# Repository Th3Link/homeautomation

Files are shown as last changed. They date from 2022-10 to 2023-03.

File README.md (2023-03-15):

# homeautomation

In this repository you can find components for a CANBus home automation system.

## mqtt_gateway
The gateway is used to access the canbus via MQTT but it also has some very useful features
for the canbus maintainance. It features a web interface (currently unencrypted http)
which enables you to make some settings for the gateway, view modify and update all your attached
devices on the can bus and update the gateway itself. It translates can messages to MQTT
and vice versa using static implemented rules.

It can also forward all can messages to MQTT for debug purposes and can send can messages
via MQTT using the "canbus/debug/<id>" topic.

The mqtt_gateway has two extension ports to hook on up to 4 relais and/or 4 sensor boards
per port. Quite powerful for mid size stand alone applications. 

### PIN assignment

## Relais
Disclaimer: It you put mains voltage on a relais, make sure that you know what you are doing.
These components are experimental and you are in charge for your onw actions. Be safe. If
you are unsure, get an expert or leave it.

Three PCBs and one software to switch power on and off. One PCB uses solid state
relais which can only be used to switch mains voltage (~230V @ 50-60Hz). Every SSR could
handle up to 1A permanent load but six SSR share one 1A fuse for protection. Be very careful
what your load is, capacitive loads or inductive loads might blow up the SSR. However, it
can savely handle small rollershutter, heating actuations and electro-magnetic contactors.

There is also a PCB with regular relais which can handle up to 16A each. There is no fuse on
the PCB, so make sure your circuits are well protected. Even if these relais can handle more
current, be careful with heavy loads such as motors, FUs and other inductive loads that can
back inject. Note that these relais do not have a deion chamber (arc quenching chamber) and
in case of changing loads, an electro-magnetic contactor might be a better choice.

The third board in specialized for rollershutter. Two relais are cascaded. The first switches
power on and the second is meant to switch between up and down. The other relais support
software rollershutter capabilities which make sure, that up and down are not active at the
same time.

They all use the same software. Tha pinning on the ESP32 is identical. All Relais PCBs
have one extension port.

### PIN assignment

## Lightswitch
The lightswitch component is one of the more advanced circuits packed with features.

## Sensors

## UART Adapter

## CAN Header

## CAN Hub

## Use cases

## Structure

## Supply Power

## CAN / TWAI

### The connector

### CAN IDs

### Message IDs

### Types

## MQTT

MQTT has a subscribe and publish communication strategy, anyone interested in a topic
will get the message when anyone makes a publish. An MQTT Message consists of a topic
and a data part. 

### MQTT to CAN
It seems logical to use this separation for the CAN messages as well.
However, there were some thought about where to put i.e. numbers of lamps or relais.

It seems best to put the identificable devices into the topic and the numbers into the
data part. When using hexadecimal numbers, they get a leading 0x. the CANID is always
in hex, additionally the BITMASK is also hex. 

#### canbus/relais_command/&lt;CANID> &lt;NO>/&lt;STATE>/&lt;TIMEOUT>
NO depends on the amount of chained relais. 
- 0-15 are onboand relais. If the PCB has only 12 relais, 12-15 are unused. 
- 16-31 is the extender with address 0b00
- 32-47 0b01
- 48-63 0b10
- 64-79 0b11
The state is 0 for OFF, 1 for ON. The TIMEOUT is in milliseconds

#### canbus/rollershutter_command/&lt;CANID> &lt;NO>/&lt;STATE>/&lt;TIMEOUT>
NO depends on the amount of chained relais. 
- 0-7 are onboand relais. If the PCB has only 12 relais, 6-7 are unused. 
- 8-15 is the extender with address 0b00
- 16-23 0b01
- 24-31 0b10
- 32-39 0b11
The state is 0 for OFF, 1 for UP, 2 for DOWN. The TIMEOUT is in milliseconds

#### canbus/lamp_command/&lt;CANID> &lt;VALUE>/&lt;BITMASK>/&lt;BANK>
The value accepts values from 0 to 255 where 0 is OFF und 255 is the maximum brightness.
The bitmask must be given in HEX, the first byte are leds 0-7 (little endian). The bitmask
musk always be 3 bytes long
- 0xFFFFFF selects all LEDs
- 0xFF0000 seletcs LEDs 0-7
- 0x010000 selects LED 0
- 0x800000 selects LED 7
- 0x000100 seletcs LED 8

#### canbus/debug/&lt;CANID> &lt;CANMESSAGE>
The CANMESSAGE must be given in HEX, and can input every message. The first byte written
in CANMESSAGE will translate to data[0] in the can message.

### CAN to MQTT
#### canbus/relais_state/&lt;CANID> &lt;NO>/&lt;STATE>
#### canbus/rollershutter_state/&lt;CANID> &lt;NO>/&lt;STATE>
#### canbus/button/&lt;CANID> &lt;BUTTONID>/&lt;EVENT>/&lt;COUNT>
The button ID depends on the amount of buttons attached to the extension board
- 0-3 maps to onboard buttons. Thed are unusen if the PCB does not have buttons.
- 4-7 maps to the extension board with address 0b00
- 8-11 0b01
- 12-15 0x10
- 16-19 0x11

#### canbus/humidity/&lt;SENSORID> &lt;HUMITIDY>
The SENSORID is a bit difficult. It has no mapping to the CANID. The Sensor ID is the
devics UID (CHIP ID on stm32 and MAC address on ESP3) appended with the pin number or
I2C address (depending on the sensor used)
The humidiy is a relative humidity in percent.

In practice just put the sensor location in your house and the according SENSORID somewhere
where it does not get lost.
 
#### canbus/temperature/&lt;SENSORID> &lt;TEMPERATURE>
For this value comes another option for the SENSORID along. DS18B20 sensors have an
own 64 bit address with 48 unique bits. When using such a sensor, these 48 bits are
the SENSORID, for other sensors its the same as for humidity.

#### canbus/log/&lt;CANID> &lt;CANMESSAGE>

## Build 
The build is done using the esp-idf (https://github.com/espressif/esp-idf), currently
in version 5.0. The idf is a huge collection of libraries and tools which increases the
development speed a lot. The documentation for the idf can be found here: 

https://docs.espressif.com/projects/esp-idf/en/latest/esp32/api-reference/index.html

The chip reference manual is also there but it was never needed for this project.
We recommend to use a linux system as development platform.
Have a look into the getting started page in the documentation.

Quick steps:

`sudo pacman -S --needed gcc git make flex bison gperf python cmake ninja ccache dfu-util libusb`

`git clone --recursive https://github.com/espressif/esp-idf.git`

`cd esp-idf`

`./install.sh esp32`

`. ./export.sh # note the dot at the beginning: source the file, otherwise you dont get the environment varibles set`

Than you can change to your project dir (i.e. homeautomation/software/mqtt_gateway) and
compile.

`idf.py build`

Programming can be done by

`idf.py flash -p /dev/ttyUSB0`

## Debugging
Sadly, the ESP32 has to few pins to support a JTAG debugger. So we are going with printf
/ ESP_LOGI debugging here and using the serial port quite a lot. The ESP also prints a
stack trace when the CPU faults, that is also helpful but still not as good as stepping through
the code and viewing every variable on the way. To connect to the serial interface we can also
use the idf command:

idf.py monitor -p /dev/ttyUSB0

idf commands can also be chained, e.g. 

idf.py build flash monitor -p /dev/ttyUSB0

### Read out partitions

## License
This project is releases under the GNU GPL 3.0. This license is rather long and difficult
to read and interpret. However, if changes are made, we like to get contribution and for the
hardware part it is best to have everything open for the most sustainability. All schematics,
layout, mechanics, tools and software is provided to fix stuff on your own rather than throwing
it away.

## Contribution
Feel free to report issues or open a merge request.

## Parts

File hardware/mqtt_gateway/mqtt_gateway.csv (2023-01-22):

Id | Designator | Package | Quantity | Designation | Supplier and ref
1 | FB1 | C_0603_1608Metric_Pad1.08x0.95mm_HandSolder | 1 | Ferrite_Bead_Small
2 | C1,C12,C5 | C_0603_1608Metric_Pad1.08x0.95mm_HandSolder | 3 | 10u
3 | C2,C3,C9,C13,C19 | C_0603_1608Metric_Pad1.08x0.95mm_HandSolder | 5 | 100n
4 | C14 | C_0402_1005Metric_Pad0.74x0.62mm_HandSolder | 1 | 470p
5 | C15,C16 | C_0402_1005Metric_Pad0.74x0.62mm_HandSolder | 2 | 1u
6 | C17,C8,C7 | C_0402_1005Metric_Pad0.74x0.62mm_HandSolder | 3 | 100n
7 | C18 | C_0603_1608Metric_Pad1.08x0.95mm_HandSolder | 1 | 20n
8 | J1 | RJ45_OST_PJ012-8P8CX_Vertical | 1 | awesome:RJ45-CAN
9 | J3 | RJ45_Amphenol_RJMG1BD3B8K1ANR | 1 | RJ45_Amphenol_RJMG1BD3B8K1ANR
10 | R6,R8,R9,R13,R28,R25 | R_0603_1608Metric_Pad0.98x0.95mm_HandSolder | 6 | 10K
11 | R7 | R_0603_1608Metric_Pad0.98x0.95mm_HandSolder | 1 | 12K1 1%
12 | R10,R11 | R_0603_1608Metric_Pad0.98x0.95mm_HandSolder | 2 | 1K
13 | U2 | SOT-223-3_TabPin2 | 1 | LD1117S33TR_SOT223
14 | U3 | SOT-23 | 1 | PESD2CAN
15 | U4 | SOIC-8_3.9x4.9mm_P1.27mm | 1 | MCP2562-E-SN
16 | U7 | QFN-24-1EP_4x4mm_P0.5mm_EP2.6x2.6mm | 1 | LAN8720A
17 | R12 | R_0603_1608Metric_Pad0.98x0.95mm_HandSolder | 1 | R
18 | H2,H3,H4,H1 | MountingHole_3.2mm_M3 | 4 | MountingHole
19 | U6 | ESP32-WROOM-32 | 1 | ESP32-WROOM-32
20 | C20 | C_0603_1608Metric_Pad1.08x0.95mm_HandSolder | 1 | 1u
21 | J4 | WAGO250-204 | 1 | WAGO250-204
22 | C4,C6 | C_0805_2012Metric_Pad1.18x1.45mm_HandSolder | 2 | 47u
23 | R2,R16 | R_0402_1005Metric_Pad0.72x0.64mm_HandSolder | 2 | 33R
24 | R18 | R_0402_1005Metric_Pad0.72x0.64mm_HandSolder | 1 | 10K
25 | R19 | R_0603_1608Metric_Pad0.98x0.95mm_HandSolder | 1 | 33R
26 | R30,R31,R29,R4,R24,R3,R1,R5 | R_0603_1608Metric_Pad0.98x0.95mm_HandSolder | 8 | 100R
27 | R32,R27,R26,R33 | R_0603_1608Metric_Pad0.98x0.95mm_HandSolder | 4 | 2K2
28 | J2,J5 | 02x03MicroMatch | 2 | Button-Sensors-MicroMatch2X03
29 | U1 | wuerthDebug6 | 1 | wuerthDebug6
30 | R20,R21,R22,R23 | R_0603_1608Metric_Pad0.98x0.95mm_HandSolder | 4 | 50R

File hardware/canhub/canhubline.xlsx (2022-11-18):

Prj: | canhubline.xml |  |  |  | Board Qty: | 1
Co.: |  |  |  |  | Unit Cost: | $3.77
Prj date: | Thu 17 Nov 2022 08:26:32 PM CET |  |  |  | Total Cost: | $3.77
$ date: | 2022-11-17 20:26:32
Global Part Info
Refs | Value | Footprint | Manf# | Qty | Unit$ | Ext$
H1-H4 | MountingHole | MountingHole_3.2mm_M3 |  | 4
J1 | WAGO250-205 | WAGO250-205 | https://cdn-reichelt.de/documents/datenblatt/C151/WAGO250-20X.pdf | 1 | 0.99 | $0.99
J2UPLINK1,J3-J13 | RJ45-CAN | RJ45_OST_PJ012-8P8CX_Vertical |  | 12 | 0.14 | $1.68
PCB | PCB | PCB |  | 1 | 1.0976 | $1.10
KiCost® v1.1.12

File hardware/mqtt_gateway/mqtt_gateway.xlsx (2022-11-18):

Prj: | mqtt_gateway.xml |  |  |  | Board Qty: | 1
Co.: |  |  |  |  | Unit Cost: | $14.42
Prj date: | Thu 17 Nov 2022 02:24:03 PM CET |  |  |  | Total Cost: | $14.42
$ date: | 2022-11-17 14:24:04
Global Part Info
Refs | Value | Footprint | Manf# | Qty | Unit$ | Ext$
C1,C5,C12 | 10u | C_0603_1608Metric_Pad1.08x0.95mm_HandSolder |  | 3 | 0.02 | $0.06
C2,C3,C9,C13,C19 | 100n | C_0603_1608Metric_Pad1.08x0.95mm_HandSolder |  | 5 | 0.02 | $0.10
C4,C6 | 47u | C_0805_2012Metric_Pad1.18x1.45mm_HandSolder |  | 2 | 0.02 | $0.04
C7,C8,C17 | 100n | C_0402_1005Metric_Pad0.74x0.62mm_HandSolder |  | 3 | 0.02 | $0.06
C14 | 470p | C_0402_1005Metric_Pad0.74x0.62mm_HandSolder |  | 1 | 0.02 | $0.02
C15,C16 | 1u | C_0402_1005Metric_Pad0.74x0.62mm_HandSolder |  | 2 | 0.02 | $0.04
C18 | 20n | C_0603_1608Metric_Pad1.08x0.95mm_HandSolder |  | 1 | 0.02 | $0.02
C20 | 1u | C_0603_1608Metric_Pad1.08x0.95mm_HandSolder |  | 1 | 0.02 | $0.02
FB1 | Ferrite_Bead_Small | C_0805_2012Metric_Pad1.18x1.45mm_HandSolder |  | 1
H1-H4 | MountingHole | MountingHole_3.2mm_M3 |  | 4
J1 | awesome:RJ45-CAN | RJ45_OST_PJ012-8P8CX_Vertical |  | 1
J2,J5 | Button-Sensors-MicroMatch2X03 | 02x03MicroMatch |  | 2 | 0.39 | $0.78
J3 | RJ45_Amphenol_RJMG1BD3B8K1ANR | RJ45_Amphenol_RJMG1BD3B8K1ANR | https://www.amphenolcanada.com/ProductSearch/Drawings/AC/RJMG1BD3B8K1ANR.PDF | 1 | 4.8 | $4.80
J4 | WAGO250-204 | WAGO250-204 | https://cdn-reichelt.de/documents/datenblatt/C151/WAGO250-20X.pdf | 1 | 0.99 | $0.99
R1,R3-R5,R24,R29-R31 | 100R | R_0603_1608Metric_Pad0.98x0.95mm_HandSolder |  | 8 | 0.02 | $0.16
R2,R16 | 33R | R_0402_1005Metric_Pad0.72x0.64mm_HandSolder |  | 2 | 0.02 | $0.04
R6,R8,R9,R13,R25,R28 | 10K | R_0603_1608Metric_Pad0.98x0.95mm_HandSolder |  | 6 | 0.02 | $0.12
R7 | 12K1 1% | R_0603_1608Metric_Pad0.98x0.95mm_HandSolder |  | 1 | 0.02 | $0.02
R10,R11 | 1K | R_0603_1608Metric_Pad0.98x0.95mm_HandSolder |  | 2 | 0.02 | $0.04
R12 | R | R_0603_1608Metric_Pad0.98x0.95mm_HandSolder |  | 1 | 0.02 | $0.02
R18 | 10K | R_0402_1005Metric_Pad0.72x0.64mm_HandSolder |  | 1 | 0.02 | $0.02
R19 | 33R | R_0603_1608Metric_Pad0.98x0.95mm_HandSolder |  | 1 | 0.02 | $0.02
R20-R23 | 50R | R_0603_1608Metric_Pad0.98x0.95mm_HandSolder |  | 4 | 0.02 | $0.08
R26,R27,R32,R33 | 2K2 | R_0603_1608Metric_Pad0.98x0.95mm_HandSolder |  | 4 | 0.02 | $0.08
U1 | wuerthDebug6 | wuerthDebug6 |  | 1
U2 | LD1117S33TR_SOT223 | SOT-223-3_TabPin2 | http://www.st.com/st-web-ui/static/active/en/resource/technical/document/datasheet/CD00000544.pdf | 1 | 0.52 | $0.52
U3 | PESD2CAN | SOT-23 |  | 1 | 0.3 | $0.30
U4 | MCP2562-E-SN | SOIC-8_3.9x4.9mm_P1.27mm | http://ww1.microchip.com/downloads/en/DeviceDoc/25167A.pdf | 1 | 1.22 | $1.22
U6 | ESP32-WROOM-32 | ESP32-WROOM-32 | https://www.espressif.com/sites/default/files/documentation/esp32-wroom-32_datasheet_en.pdf | 1 | 2.77 | $2.77
U7 | LAN8720A | QFN-24-1EP_4x4mm_P0.5mm_EP2.6x2.6mm | http://ww1.microchip.com/downloads/en/DeviceDoc/8720a.pdf | 1
PCB | PCB | PCB |  | 1 | 2.084245283 | $2.08
KiCost® v1.1.12

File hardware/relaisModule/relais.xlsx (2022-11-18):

Prj: | relais.xml |  |  |  | Board Qty: | 1
Co.: |  |  |  |  | Unit Cost: | $52.89
Prj date: | Thu 17 Nov 2022 08:06:38 PM CET |  |  |  | Total Cost: | $52.89
$ date: | 2022-11-17 20:06:39
Global Part Info
Refs | Value | Footprint | Manf# | Qty | Unit$ | Ext$
A1,A2 | SolderJumper_3_Bridged12 | SolderJumper-3_P1.3mm_Open_RoundedPad1.0x1.5mm |  | 2
C1,C4,C5,C8-C11 | 100n | C_0603_1608Metric_Pad1.08x0.95mm_HandSolder |  | 7 | 0.02 | $0.14
C2 | 1u | C_0603_1608Metric_Pad1.08x0.95mm_HandSolder |  | 1 | 0.02 | $0.02
C3,C6,C7 | 10u | C_0805_2012Metric_Pad1.18x1.45mm_HandSolder |  | 3 | 0.02 | $0.06
D1,D3,D5,D7,D9,D11,D13,D15,D17,D19,D21,D23 | 1N4148WS | D_SOD-123 | https://www.vishay.com/docs/85751/1n4148ws.pdf | 12 | 0.04 | $0.48
D2,D4,D6,D8,D10,D12,D14,D16,D18,D20,D22,D24 | LED | LED_0603_1608Metric_Pad1.05x0.95mm_HandSolder |  | 12 | 0.04 | $0.48
H1-H3,H5 | MountingHole | MountingHole_3.2mm_M3_DIN965 |  | 4
J1 | Button-Sensors-MicroMatch2X03 | 02x03MicroMatch |  | 1
J2,J4,J8-J11 | WAGO2604-1104 | WAGO2604-1104 |  | 6 | 3.25 | $19.50
J5,J6 | IRDA | PinHeader_1x03_P2.54mm_Vertical |  | 2
J7,J12 | RJ45-CAN | RJ45_OST_PJ012-8P8CX_Vertical |  | 2
J13 | WAGO2604-1102 | WAGO2604-1102 |  | 0 | 1.8 | $0.00
JP2 | SolderJumper_2_Bridged | SolderJumper-2_P1.3mm_Open_RoundedPad1.0x1.5mm |  | 1
JP5,JP6 | SolderJumper_2_Open | SolderJumper-2_P1.3mm_Open_RoundedPad1.0x1.5mm |  | 2
K1-K12 | RT314A12 | Relay_SPDT_Schrack-RT1-16A-FormC_RM5mm | https://www.te.com/commerce/DocumentDelivery/DDEController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 | 12 | 2 | $24.00
PS1 | IRM-02-12 | Converter_ACDC_MeanWell_IRM-02-xx_THT | https://www.meanwell.com/Upload/PDF/IRM-02/IRM-02-SPEC.PDF | 1
R4,R14,R21 | 10K | R_0603_1608Metric_Pad0.98x0.95mm_HandSolder |  | 3 | 0.02 | $0.06
R5,R20 | 2K2 | R_0603_1608Metric_Pad0.98x0.95mm_HandSolder |  | 2 | 0.02 | $0.04
R6-R13,R22-R25 | 1K | R_0603_1608Metric_Pad0.98x0.95mm_HandSolder |  | 12 | 0.02 | $0.24
R15 | 4K7 | R_0603_1608Metric_Pad0.98x0.95mm_HandSolder |  | 1 | 0.02 | $0.02
R16-R19 | 100R | R_0603_1608Metric_Pad0.98x0.95mm_HandSolder |  | 4 | 0.02 | $0.08
R27 | R | R_0603_1608Metric_Pad0.98x0.95mm_HandSolder |  | 1 | 0 | $0.00
U1 | PESD2CAN | SOT-23 |  | 1 | 0.32 | $0.32
U2 | MCP2562-E-SN | SOIC-8_3.9x4.9mm_P1.27mm | http://ww1.microchip.com/downloads/en/DeviceDoc/25167A.pdf | 1 | 1.22 | $1.22
U3 | ESP32-WROOM-32 | ESP32-WROOM-32 | https://www.espressif.com/sites/default/files/documentation/esp32-wroom-32_datasheet_en.pdf | 1 | 2.77 | $2.77
U4 | MCP1703A-3302_SOT89 | SOT-89-3_Handsoldering | http://ww1.microchip.com/downloads/en/DeviceDoc/20005122B.pdf | 1 | 0.84 | $0.84
U5,U6 | PCA9534 | SOIC-16W_7.5x10.3mm_P1.27mm | http://www.nxp.com/documents/data_sheet/PCF8574_PCF8574A.pdf | 2 | 1 | $2.00
U7,U8 | TPL7407LADR | SO-16_5.3x10.2mm_P1.27mm | http://www.ti.com/lit/ds/symlink/uln2003a.pdf | 2 | 0.31 | $0.62
U9 | wuerthDebug6 | wuerthDebug6 |  | 1
PCB | PCB |  |  | 1 | 2.944245283 | $2.94
KiCost® v1.1.12

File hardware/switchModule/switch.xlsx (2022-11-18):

Prj: | switch.xml |  |  |  | Board Qty: | 1
Co.: |  |  |  |  | Unit Cost: | $8.35
Prj date: | Thu 17 Nov 2022 08:19:28 PM CET |  |  |  | Total Cost: | $8.35
$ date: | 2022-11-17 20:19:29
Global Part Info
Refs | Value | Footprint | Manf# | Qty | Unit$ | Ext$
C1,C4,C8-C11 | 100n | C_0603_1608Metric_Pad1.08x0.95mm_HandSolder |  | 6 | 0.02 | $0.12
C2 | 1u | C_0603_1608Metric_Pad1.08x0.95mm_HandSolder |  | 1 | 0.02 | $0.02
C3,C6,C7,C12 | 10u | C_0603_1608Metric_Pad1.08x0.95mm_HandSolder |  | 4 | 0.02 | $0.08
C13,CBST1,CFF1 | C | C_0603_1608Metric_Pad1.08x0.95mm_HandSolder |  | 3 | 0.02 | $0.06
D1,D4 | D | D_SOD-123 |  | 2
J1,J3 | Button-Sensors-MicroMatch2X03 | 02x03MicroMatch |  | 2 | 0.39 | $0.78
J2 | Screw_Terminal_01x02 | TerminalBlock_RND_205-00001_1x02_P5.00mm_Horizontal |  | 1
J5,J6 | IRDA | PinHeader_1x03_P2.54mm_Vertical |  | 2
J7 | RJ45-CAN | RJ45_OST_PJ012-8P8CX_Vertical |  | 1 | 0.14 | $0.14
J8-J11 | Conn_01x06_Female | 02x03MicroMatch |  | 4
L1 | L | L_1210_3225Metric_Pad1.42x2.65mm_HandSolder |  | 1
R4,R7,R9,R11,R13 | 10K | R_0603_1608Metric_Pad0.98x0.95mm_HandSolder |  | 5 | 0.02 | $0.10
R5,R6 | 2K2 | R_0603_1608Metric_Pad0.98x0.95mm_HandSolder |  | 2 | 0.02 | $0.04
R15 | 4K7 | R_0603_1608Metric_Pad0.98x0.95mm_HandSolder |  | 1 | 0.02 | $0.02
R16-R19,R21-R24,R35-R38 | 100R | R_0603_1608Metric_Pad0.98x0.95mm_HandSolder |  | 12 | 0.02 | $0.24
R25 | 100K | R_0603_1608Metric_Pad0.98x0.95mm_HandSolder |  | 1 | 0.02 | $0.02
R27 | R | R_0603_1608Metric_Pad0.98x0.95mm_HandSolder |  | 1
RESR1,RFB1,RFB2,RRON1 | ?R | R_0603_1608Metric_Pad0.98x0.95mm_HandSolder |  | 4
SW1-SW4 | SW_Push | SW_SPST_TL3305A |  | 4 | 0.177 | $0.71
U1 | PESD2CAN | SOT-23 |  | 1 | 0.32 | $0.32
U2 | MCP2562-E-SN | SOIC-8_3.9x4.9mm_P1.27mm | http://ww1.microchip.com/downloads/en/DeviceDoc/25167A.pdf | 1 | 1.22 | $1.22
U3 | ESP32-WROOM-32 | ESP32-WROOM-32 | https://www.espressif.com/sites/default/files/documentation/esp32-wroom-32_datasheet_en.pdf | 1 | 2.77 | $2.77
U4 | MCP1703A-3302_SOT89 | SOT-89-3_Handsoldering | http://ww1.microchip.com/downloads/en/DeviceDoc/20005122B.pdf | 1 | 0.84 | $0.84
U5 | LM5163 | Texas_R-PDSO-G8_EP2.95x4.9mm_Mask2.4x3.1mm_ThermalVias |  | 1
U6 | wuerthDebug6 | wuerthDebug6 |  | 1
PCB |  |  |  | 1 | 0.874245283 | $0.87
KiCost® v1.1.12

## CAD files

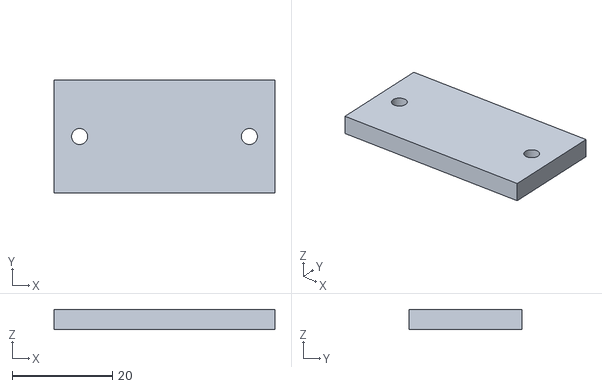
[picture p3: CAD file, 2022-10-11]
mechanics/canhub/clip_spacer.stl
44.0 x 22.5 x 4.00

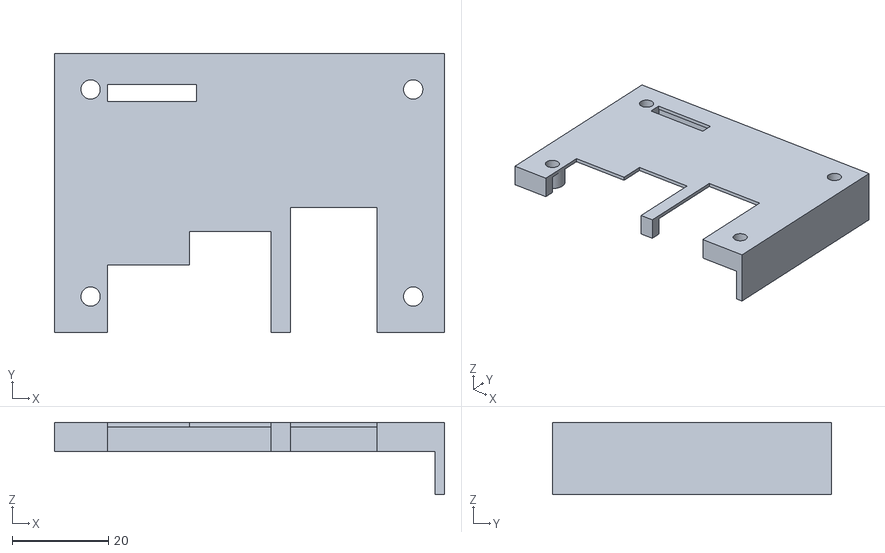
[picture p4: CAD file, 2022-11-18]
mechanics/mqtt_gateway/mqtt_gateway_lid.stl
81.0 x 58.0 x 15.0

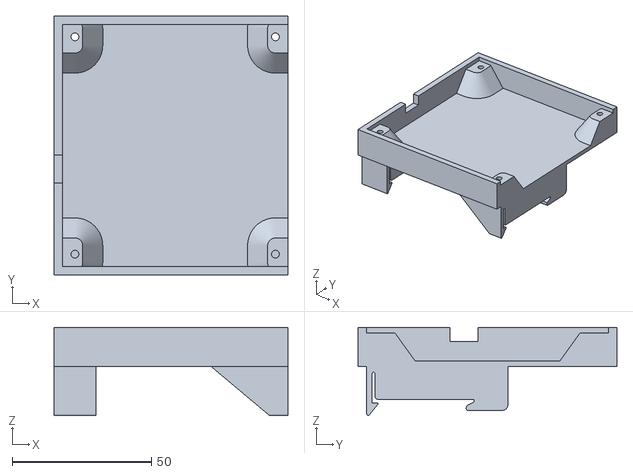
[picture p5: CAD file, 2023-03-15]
mechanics/pwm_adapter/pwm_adapter_bottom.stl
84.0 x 93.0 x 31.6

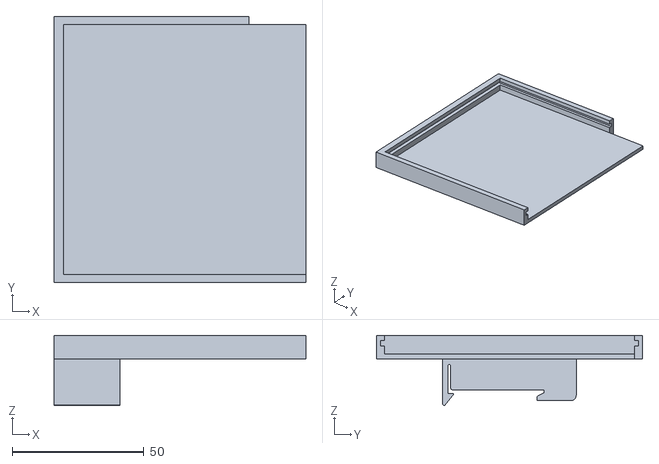
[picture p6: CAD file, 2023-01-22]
mechanics/relais/relais_single.stl
95.5 x 101.0 x 26.6

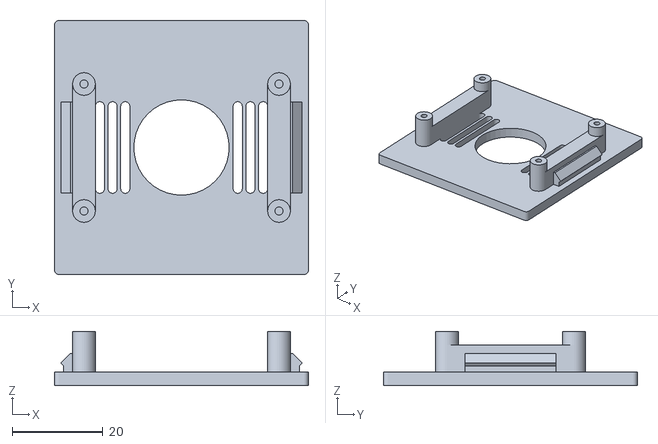
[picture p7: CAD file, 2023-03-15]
mechanics/sensor/sensor_berker_pir_bme680.stl
56.0 x 56.0 x 12.0

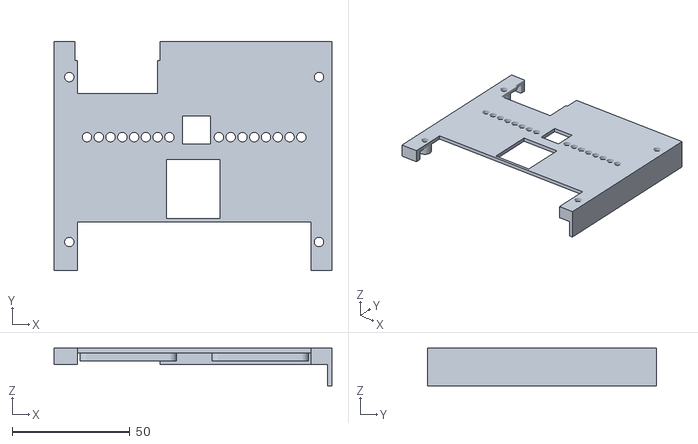
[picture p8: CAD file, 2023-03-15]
mechanics/ssr/ssr_lid.stl
118.0 x 97.0 x 16.0

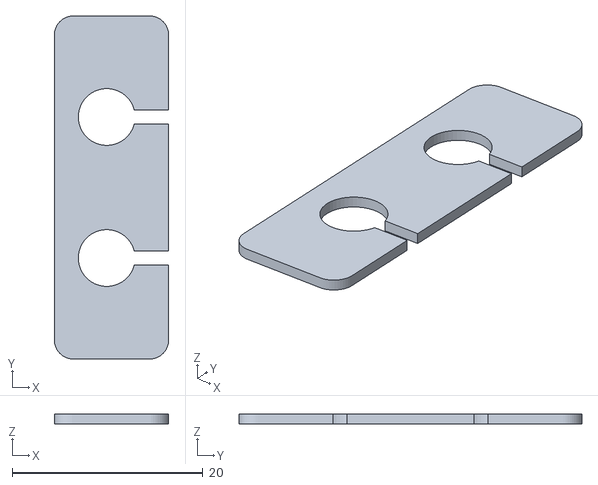
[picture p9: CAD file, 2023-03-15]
mechanics/switch/spacer_berker.stl
12.0 x 36.0 x 1.00

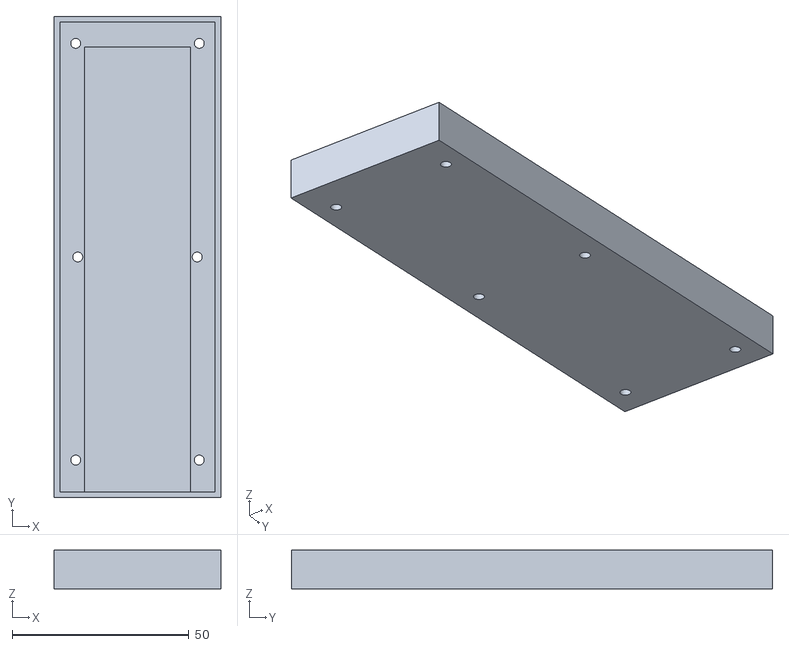
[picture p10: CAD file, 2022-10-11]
mechanics/canhub/housing.stl
47.2 x 136.2 x 11.0

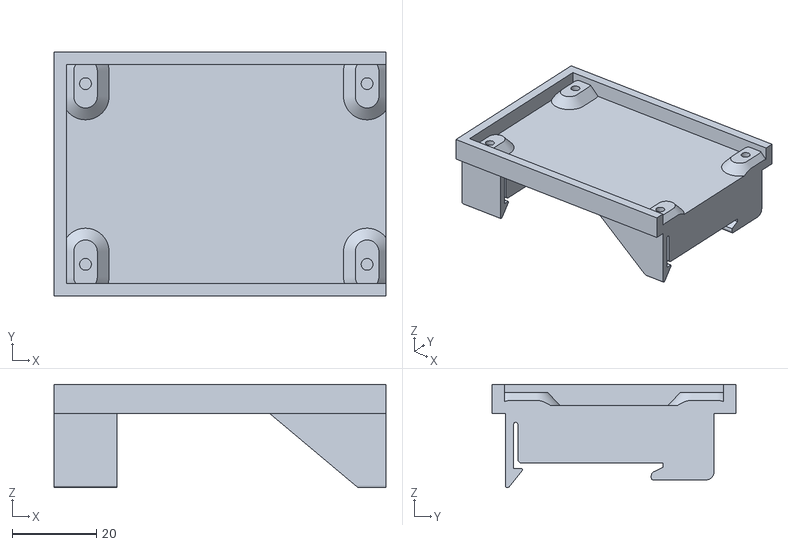
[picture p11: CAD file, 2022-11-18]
mechanics/mqtt_gateway/mqtt_gateway_bottom.stl
79.0 x 58.0 x 24.6

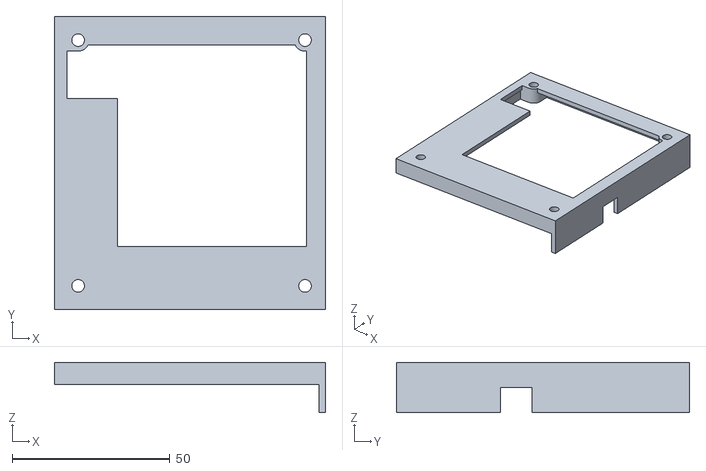
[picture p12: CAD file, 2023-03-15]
mechanics/pwm_adapter/pwm_adapter_lid.stl
86.0 x 93.0 x 16.0

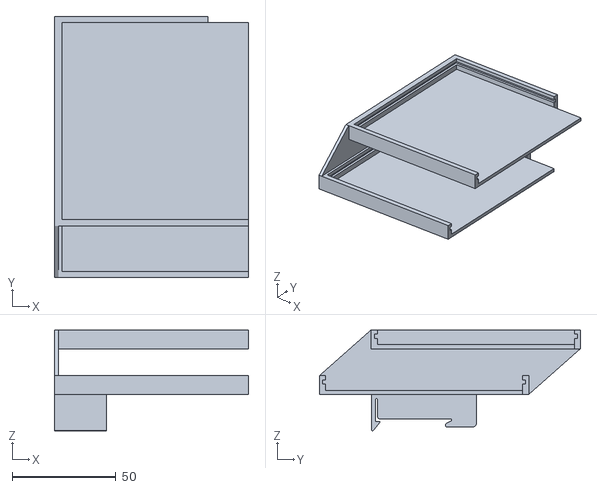
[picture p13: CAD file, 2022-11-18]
mechanics/relais/relais.stl
93.5 x 126.0 x 48.6

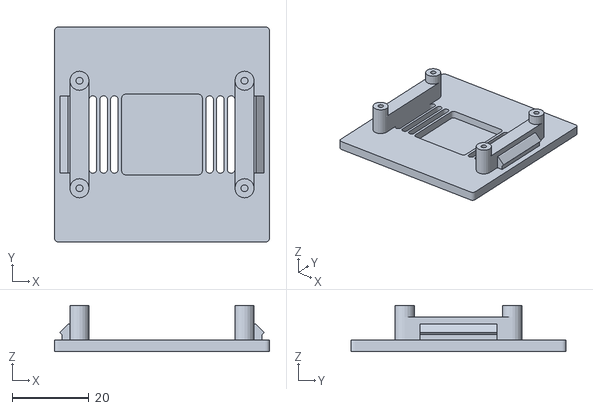
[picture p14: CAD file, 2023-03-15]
mechanics/sensor/sensor_berker_nightlight_bme680.stl
56.0 x 56.0 x 12.0

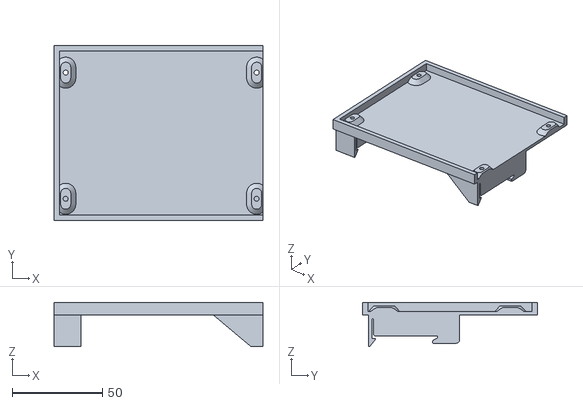
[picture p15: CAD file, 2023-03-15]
mechanics/ssr/ssr_bottom.stl
116.0 x 97.0 x 24.6

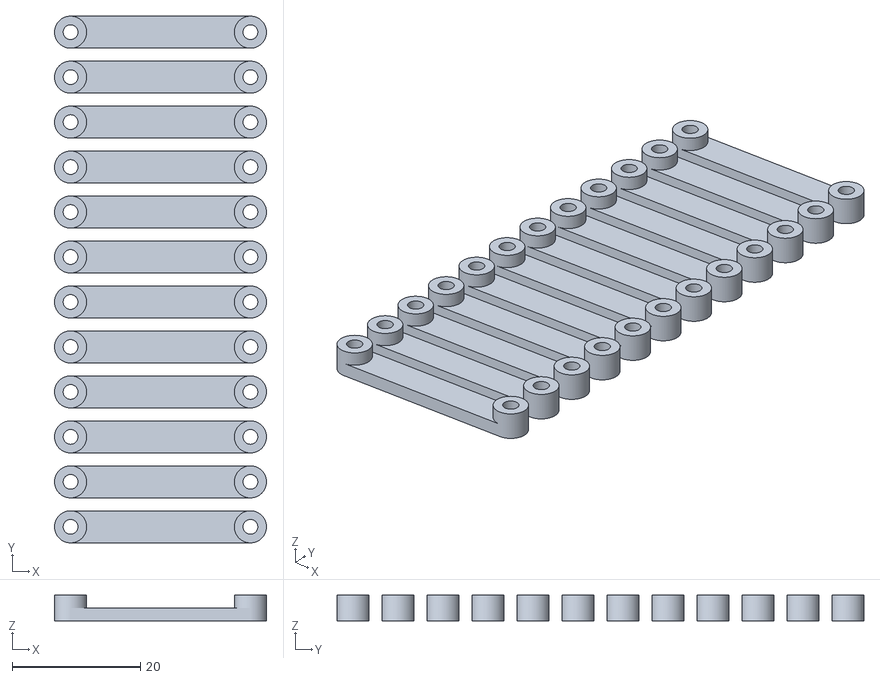
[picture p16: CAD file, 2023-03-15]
mechanics/switch/12x_spacer_v2.stl
33.0 x 82.0 x 4.00

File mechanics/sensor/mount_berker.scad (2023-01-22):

$fn=50;
hole_dx = 32;
hole_dy = 14.8;
hole_r = 2.98;
hole_h = 10;

plate_h = 71;
plate_h2 = 55;
plate_r = 78/2;
plate_holes_r = 30;
plate_holes_rk = 3.4/2;
plate_holes_rg = 5.5/2;
plate_holes_len = 15;
plate_t = 1.7;

switch_x = 5;
switch_y = 5;
switch_z = 2;
switch_dx = 32;
switch_dy = 25;

pcd_mount_r = 1.8/2;
pcb_mount_dx = 28;
pcb_mount_dy = 43;

module slottedCylinder(r,h,rot=0)
{
    cylinder(r=r,h=h);
    rotate([0,0,rot]) translate([-r*2+1,0,h/2]) cube([r*4,r/2,h], center=true);
}

module holes(h) {
    slottedCylinder(r=hole_r,h=h,rot=180);
    translate([hole_dx,0,0]) slottedCylinder(r=hole_r,h=h);
    translate([0,hole_dy,0]) slottedCylinder(r=hole_r,h=h,rot=180);
    translate([hole_dx,hole_dy,0]) slottedCylinder(r=hole_r,h=h);
    
}

module mountRing() {
    scale([1,1,0.5]) minkowski() {
        intersection() {
            difference() {
                cylinder(r=plate_holes_r+0.01,h=plate_t);
                cylinder(r=plate_holes_r-0.01,h=plate_t);
            }
            translate([0,-plate_holes_r,plate_t/2]) cube([plate_holes_len,10,plate_t], center=true);
        }
        cylinder(r=plate_holes_rk,h=plate_t);
    }
    rotate([0,0,-13]) translate([0,-plate_holes_r]) cylinder(r=plate_holes_rg,h=plate_t);
}

module roundovercube(v,r, center=false) {
    
    translate([0,0,-v[2]*0.25]) scale([1,1,0.5]) minkowski() {
        cube([v[0],v[1],v[2]],center=center);
        cylinder(r=r,h=v[2]);
    }
}

module blocks(b,h,height=hole_h+plate_t) {
    translate([plate_h/2-15.5,plate_h/2,height/2]) roundovercube([b,h,height], 2, center=true);
    translate([plate_h/2+15.5,plate_h/2,height/2]) roundovercube([b,h,height], 2, center=true);
}

module switches() {
    translate([-switch_dx/2-switch_x/2,-switch_dy/2-switch_y/2,0]) union() {
        cube([switch_x,switch_y,switch_z]);
        translate([0,switch_dy,0]) cube([switch_x,switch_y,switch_z]);
        translate([switch_dx,0,0]) cube([switch_x,switch_y,switch_z]);
        translate([switch_dx,switch_dy,0]) cube([switch_x,switch_y,switch_z]);
    }
}

module pcb_mount(r,h)
{
    translate([-pcb_mount_dx/2,-pcb_mount_dy/2,0]) union() {
        cylinder(r=r,h=h);
        translate([0,pcb_mount_dy,0]) cylinder(r=r,h=h);
        translate([pcb_mount_dx,0,0]) cylinder(r=r,h=h);
        translate([pcb_mount_dx,pcb_mount_dy,0]) cylinder(r=r,h=h);
    }
}

module hcube(v,h1, h2)
{
    cube(v, center=true);
    translate([-v[0]/2+v[1]/2,0,0.75]) cube([v[1],h1,v[2]*1.5],center=true);
    translate([+v[0]/2-v[1]/2,0,0.75]) cube([v[1],h2,v[2]*1.5],center=true);
}

module plate() {
    intersection() {
        translate([0,(plate_h-plate_h2)/2,0]) cube([plate_h,plate_h2,plate_t]);
        translate([plate_h/2,plate_h/2,0]) cylinder(r=plate_r,h=plate_t);
    }
}

module blocks_with_holes(height) {
    translate([-14,-17.5,0]) difference() {
    blocks(8,32, height);
    translate([plate_h/2-hole_dx/2,plate_h/2-hole_dy/2,0]) holes(h=height);
    }
}

difference() {
union() {
    difference() {
    blocks(8,32);
    translate([plate_h/2-hole_dx/2,plate_h/2-hole_dy/2,0]) holes(h=hole_h+plate_t);
    }
    difference() {
        union() {
            plate();
            translate([plate_h/2,plate_h/2,0]) pcb_mount(3.5,4);
        }
        translate([plate_h/2,plate_h/2,0]) union() {
            //mountRing();
            rotate([0,0,90]) mountRing();
            //rotate([0,0,180]) mountRing();
            rotate([0,0,270])mountRing();
        }
        blocks(14,34);
    }
    translate([plate_h/2,plate_h/2,1.5]) hcube([plate_holes_r*2-6,2,3], 8,8);
    translate([plate_h/2,plate_h/2,1.5]) cube([10,10,3], center=true);
    translate([plate_h/2,plate_h/2,1.5]) rotate([0,0,90]) hcube([55,8,3],8,8);
}
//translate([plate_h/2,plate_h/2,0]) switches();
translate([plate_h/2,plate_h/2,0]) pcb_mount(pcd_mount_r,10);
}

difference() {
translate([plate_h/2,plate_h/2,plate_t]) rotate([0,0,90]) union() {
translate([-52/2,-20/2,0]) cube([3,20,1]);
translate([52/2-3,-20/2,0]) cube([3,20,1]);
// clamps for the frame
translate([-51.6/2+1.5,-20/2,2]) rotate([-90,0,0]) cylinder(r=4/2,h=20);
translate([51.6/2-3+1.5,-20/2,2]) rotate([-90,0,0]) cylinder(r=4/2,h=20);
}
}

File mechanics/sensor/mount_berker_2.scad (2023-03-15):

$fn=40;
outer_x = 70;
outer_y = 72;
inner_x = 53;
inner_y = 55;
radius = 1;
t=2;
spacer=9;

module base(outer_x,outer_y,t,radius) {
    hull() {
        translate([-outer_x/2+1,-outer_y/2+1,0]) cylinder(r=radius, h=t);
        translate([-outer_x/2+1,outer_y/2-1,0]) cylinder(r=radius, h=t);
        translate([outer_x/2-1,outer_y/2-1,0]) cylinder(r=radius, h=t);
        translate([outer_x/2-1,-outer_y/2+1,0]) cylinder(r=radius, h=t);
    }
}

module side_clip_hook(clamp_edge, length=20)
{
    difference() {
       union () {
    fill_cube_side= sqrt(clamp_edge*clamp_edge*2)/2;
    translate([0,0,fill_cube_side]) {
        rotate([0,45,0]) translate([-clamp_edge/2,-length/2,-clamp_edge/2]) cube([clamp_edge,length,clamp_edge]);
        translate([0,-length/2,0]) cube([fill_cube_side,length,fill_cube_side]);
    }
    translate([-1.4,(-length)/2,0]) cube([3,length,2]);
    }
    translate([0,-length/2,0]) cube([10,length,10]);
    translate([-4,-length/2,3]) cube([10,length,10]);
}
}

module side_clips(clamp_edge=3,length=20) {
    translate([-49.0/2,0,t]) {
        side_clip_hook(3, length);
    }
    translate([49.0/2,0,t]) {
        mirror([1,0,0]) side_clip_hook(3, length);
    }
}

module mounting_slot(r2,r,h,w) {
    hull() {
    translate([0,w/2-r,0]) cylinder(r=r,h=h);
    translate([0,-w/2+r,0]) cylinder(r=r,h=h);
    }
}

difference() {
    //round corner cube (plate)
    union() {
        difference() {
            base(outer_x,outer_y,t,radius);
            base(inner_x,inner_y,t,radius);
            translate([30,0,0]) mounting_slot(5/2,3/2,t,10);
            translate([-30,0,0])mounting_slot(5/2,3/2,t,10);
        }
        translate([-inner_x/2-1.0,3+16.5,0]) translate([-3,-3,0]) cube([6,6,t]);
        translate([-inner_x/2-1.0,-(3+16.5),0]) translate([-3,-3,0]) cube([6,6,t]);
        translate([inner_x/2+1.0,3+16.5,0]) translate([-3,-3,0]) cube([6,6,t]);
        translate([inner_x/2+1.0,-(3+16.5),0]) translate([-3,-3,0]) cube([6,6,t]);
        translate([0,-3-16.5,0]) side_clips(length=6);
        translate([0,+3+16.5,0]) side_clips(length=6);
        
    }
}

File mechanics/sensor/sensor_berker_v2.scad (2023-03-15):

$fn=80;
outer = 55.5;
radius = 1;
t=3;
spacer=9;

dht22=1;
pir=0;
nightlight=1;
vents=0;

module vents(l=20,r=1,t=3,d=1.5) {
    iterations=3;
    translate([-(iterations*(2*r)+(iterations-1)*d)/2,0,0])
    for ( i = [0 : iterations-1] ) {
        translate([r+(2*r+d)*i,-(l/2-r),0]) hull() {
        cylinder(r=1,h=3);
        translate([0,l-2*r,0]) cylinder(r=1,h=3);
        }
    }
}

module base(outer,t,radius) {
    hull() {
        translate([-outer/2+1,-outer/2+1,0]) cylinder(r=radius, h=t);
        translate([-outer/2+1,outer/2-1,0]) cylinder(r=radius, h=t);
        translate([outer/2-1,outer/2-1,0]) cylinder(r=radius, h=t);
        translate([outer/2-1,-outer/2+1,0]) cylinder(r=radius, h=t);
    }
}

module pcb_mount_holes(dist_x,dist_y,r,h) {
    translate([dist_x/2,0,0])
    {
        translate([0,dist_y/2,0]) cylinder(r=r,h=h);
        translate([0,-dist_y/2,0]) cylinder(r=r,h=h);
    }
    translate([-dist_x/2,0,0])
    {
        translate([0,dist_y/2,0]) cylinder(r=r,h=h);
        translate([0,-dist_y/2,0]) cylinder(r=r,h=h);
    }
}

module pcb_mount_spacer_side(dist_y,r,h)
{
        translate([0,-dist_y/2,0]) cylinder(r=r,h=h);
        translate([0,dist_y/2,0]) cylinder(r=r,h=h);
}

module pcb_mount_spacer(dist_x,dist_y,r,h,t) {
            hull() {
                translate([-dist_x/2,0,0]) pcb_mount_spacer_side(dist_y=dist_y,r=r,h=h);
            }
            hull() {
                translate([dist_x/2,0,0]) pcb_mount_spacer_side(dist_y=dist_y,r=r,h=h);
            }
            translate([-dist_x/2,0,h]) pcb_mount_spacer_side(dist_y=dist_y,r=r,h=t);
            translate([dist_x/2,0,h]) pcb_mount_spacer_side(dist_y=dist_y,r=r,h=t);
}

module side_clip_hook(clamp_edge, length=20)
{
    translate([0,0,-0.8]) difference() {
       union () {
    fill_cube_side= sqrt(clamp_edge*clamp_edge*2)/2;
    translate([0.3,0,fill_cube_side]) {
        rotate([0,45,0]) translate([-clamp_edge/2,-length/2,-clamp_edge/2]) cube([clamp_edge,length,clamp_edge]);
        //translate([0,-length/2,0]) cube([fill_cube_side,length,fill_cube_side]);
    }
    translate([-1.4,(-length)/2,0]) cube([3,length,2]);
    }
    translate([1,-length/2,0]) cube([10,length,10]);
    translate([-3,-length/2,3]) cube([10,length,10]);
}
}

module side_clips(clamp_edge=3,length=20) {
    translate([-49.3/2,0,t]) {
        side_clip_hook(3, length);
    }
    translate([49.3/2,0,t]) {
        mirror([1,0,0]) side_clip_hook(3, length);
    }
}

module nightlight_square(d=20) {
    base(d,3,1);
}

difference() {
    //round corner cube (plate)
    union() {
        base(outer,t,radius);
        pcb_mount_spacer(dist_x=43,dist_y=28,r=5/2,h=spacer,t=t);
        rotate([0,0,90]) {
        translate([0,-3-16,0]) side_clips(length=6);
        translate([0,+3+16,0]) side_clips(length=6);
        }
    }
    translate([0,0,0.5]) { 
        translate([-25,3.5+16,0]) translate([-2,-3.5,0]) cube([4,7,t]);
        translate([-25,-(3.5+16),0]) translate([-2,-3.5,0]) cube([4,7,t]);
        translate([25,3.5+16,0]) translate([-2,-3.5,0]) cube([4,7,t]);
        translate([25,-(3.5+16),0]) translate([-2,-3.5,0]) cube([4,7,t]);
    }
    if (pir==1)
    {
    // bore for the pir
    cylinder(r=21/2,h=t);
    }
    
    if (dht22==1)
    {
    // hole for dht22
    translate([-10,21/2,0.8]) cube([20.5,15.5,t]);
    translate([-10+4.5,21/2+1,0]) cube([20.5-5.5,15.5-2,0.8]);
    }
    
    if (nightlight==1)
    {
        translate([0,0,0.5]) nightlight_square();
    }
    if (vents==1)
    {
        //holes for ventilation
        translate([14.5+0.7,0,0]) vents(t=t,d=1,r=0.9);
        translate([-14.5-0.7,0,0]) vents(t=t,d=1,r=0.9);
    }
    // holes in the plate for the pcb mount (for longer screws since i dont have shorter ones here)
    translate([0,0,0.5]) pcb_mount_holes(dist_x=43,dist_y=28,r=1.8/2,h=spacer+t);
}

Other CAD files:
mechanics/sensor/sensor_berker_pir_dht22_bme680.stl
mechanics/switch/mount_berker_2.stl
mechanics/sensor/sensor_berker_dht22.stl
mechanics/switch/spacer_v2.stl
mechanics/canhub/clip_spacer.scad
mechanics/canhub/housing.scad
mechanics/legacy_ssr/legacy_ssr_bottom.scad
mechanics/legacy_ssr/legacy_ssr_bottom.stl
mechanics/legacy_ssr/legacy_ssr_lid.stl
mechanics/mqtt_gateway/mqtt_gateway_bottom.scad
mechanics/pwm_adapter/pwm_adapter.scad
mechanics/relais/relais.scad
mechanics/relais/relais_single.scad
mechanics/sensor/sensor_berker.scad
mechanics/sensor/sensor_berker.stl
mechanics/sensor/sensor_berker_bme280.stl
mechanics/sensor/sensor_berker_bme680.stl
mechanics/sensor/sensor_berker_dht22_bme680.stl
mechanics/sensor/sensor_berker_pir_bme280.stl
mechanics/sensor/sensor_berker_v2.stl
mechanics/sensor/sensor_berker_v2_dht22.stl
mechanics/ssr/ssr_bottom.scad
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

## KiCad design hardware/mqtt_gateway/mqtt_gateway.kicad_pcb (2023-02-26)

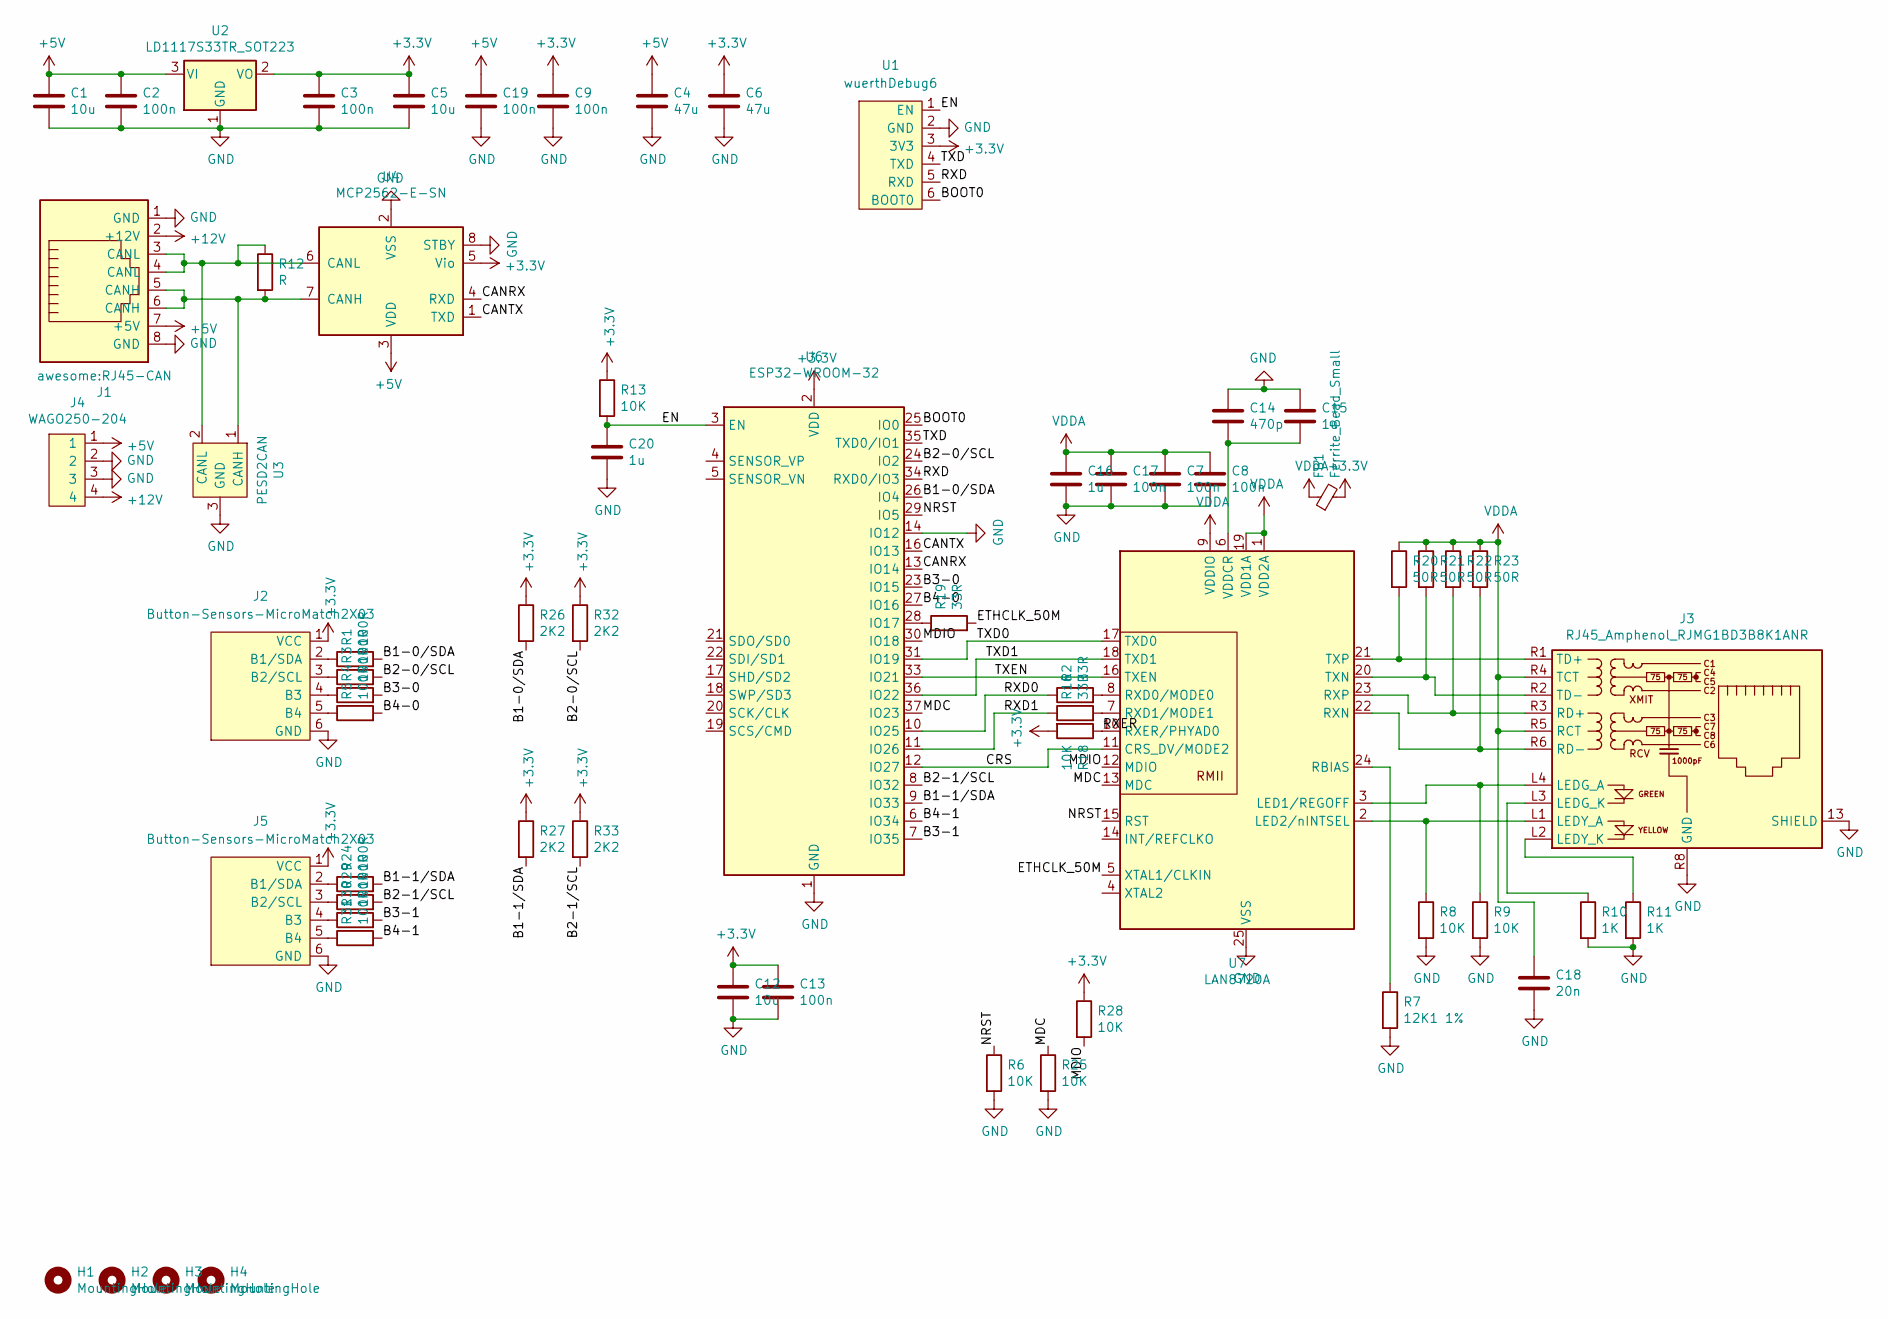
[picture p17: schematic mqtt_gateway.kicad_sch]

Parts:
C1, C5, C12: 10u; C_0603_1608Metric_Pad1.08x0.95mm_HandSolder
C2, C3, C9, C13, C19: 100n; C_0603_1608Metric_Pad1.08x0.95mm_HandSolder
C4, C6: 47u; C_0805_2012Metric_Pad1.18x1.45mm_HandSolder
C7, C8, C17: 100n; C_0402_1005Metric_Pad0.74x0.62mm_HandSolder
C14: 470p; C_0402_1005Metric_Pad0.74x0.62mm_HandSolder
C15, C16: 1u; C_0402_1005Metric_Pad0.74x0.62mm_HandSolder
C18: 20n; C_0603_1608Metric_Pad1.08x0.95mm_HandSolder
C20: 1u; C_0603_1608Metric_Pad1.08x0.95mm_HandSolder
FB1: Ferrite_Bead_Small; C_0603_1608Metric_Pad1.08x0.95mm_HandSolder
H1, H2, H3, H4: MountingHole; MountingHole_3.2mm_M3
J1: awesome:RJ45-CAN; RJ45_OST_PJ012-8P8CX_Vertical
J2, J5: Button-Sensors-MicroMatch2X03; 02x03MicroMatch
J3: RJ45_Amphenol_RJMG1BD3B8K1ANR
J4: WAGO250-204
R1, R3, R4, R5, R24, R29, R30, R31: 100R; R_0603_1608Metric_Pad0.98x0.95mm_HandSolder
R2, R16: 33R; R_0402_1005Metric_Pad0.72x0.64mm_HandSolder
R6, R8, R9, R13, R25, R28: 10K; R_0603_1608Metric_Pad0.98x0.95mm_HandSolder
R7: 12K1 1%; R_0603_1608Metric_Pad0.98x0.95mm_HandSolder
R10, R11: 1K; R_0603_1608Metric_Pad0.98x0.95mm_HandSolder
R12: R; R_0603_1608Metric_Pad0.98x0.95mm_HandSolder
R18: 10K; R_0402_1005Metric_Pad0.72x0.64mm_HandSolder
R19: 33R; R_0603_1608Metric_Pad0.98x0.95mm_HandSolder
R20, R21, R22, R23: 50R; R_0603_1608Metric_Pad0.98x0.95mm_HandSolder
R26, R27, R32, R33: 2K2; R_0603_1608Metric_Pad0.98x0.95mm_HandSolder
U1: wuerthDebug6
U2: LD1117S33TR_SOT223; SOT-223-3_TabPin2
U3: PESD2CAN; SOT-23
U4: MCP2562-E-SN; SOIC-8_3.9x4.9mm_P1.27mm
U6: ESP32-WROOM-32
U7: LAN8720A; QFN-24-1EP_4x4mm_P0.5mm_EP2.6x2.6mm

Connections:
+3.3V: C3.1, C5.1, C6.1, C9.1, C12.1, C13.1, FB1.2, J2.1 (VCC), J5.1 (VCC), R13.1, R18.2, R26.1, R27.1, R28.1, R32.1, R33.1, U1.3 (3V3), U2.2 (VO), U4.5 (Vio), U6.2 (VDD)
+5V: C1.1, C2.1, C4.1, C19.1, J1.7 (+5V), J4.1, U2.3 (VI), U4.3 (VDD)
+12V: J1.2 (+12V), J4.4
/B1-0/SDA: R1.2, R26.2, U6.26 (IO4)
/B1-1/SDA: R24.2, R27.2, U6.9 (IO33)
/B2-0/SCL: R3.2, R32.2, U6.24 (IO2)
/B2-1/SCL: R29.2, R33.2, U6.8 (IO32)
/B3-0: R4.2, U6.23 (IO15)
/B3-1: R30.2, U6.7 (IO35)
/B4-0: R5.2, U6.27 (IO16)
/B4-1: R31.2, U6.6 (IO34)
/BOOT0: U1.6 (BOOT0), U6.25 (IO0)
/CANRX: U4.4 (RXD), U6.13 (IO14)
/CANTX: U4.1 (TXD), U6.16 (IO13)
/CRS: U6.12 (IO27), U7.11 (CRS_DV/MODE2)
/EN: C20.1, R13.2, U1.1 (EN), U6.3 (EN)
/ETHCLK_50M: R19.2, U7.5 (XTAL1/CLKIN)
/MDC: R25.1, U6.37 (IO23), U7.13 (MDC)
/MDIO: R28.2, U6.30 (IO18), U7.12 (MDIO)
/NRST: R6.1, U6.29 (IO5), U7.15 (RST)
/RXD: U1.5 (RXD), U6.34 (RXD0/IO3)
/RXD0: R2.1, U6.10 (IO25)
/RXD1: R16.1, U6.11 (IO26)
/RXER: R18.1, U7.10 (RXER/PHYAD0)
/TXD: U1.4 (TXD), U6.35 (TXD0/IO1)
/TXD0: U6.31 (IO19), U7.17 (TXD0)
/TXD1: U6.36 (IO22), U7.18 (TXD1)
/TXEN: U6.33 (IO21), U7.16 (TXEN)
GND: C1.2, C2.2, C3.2, C4.2, C5.2, C6.2, C7.2, C8.2, C9.2, C12.2, C13.2, C14.1, C15.1, C16.2, C17.2, C18.2, C19.2, C20.2, J1.1 (GND), J1.8 (GND), J2.6 (GND), J3.13 (SHIELD), J3.R8 (GND), J4.2, J4.3, J5.6 (GND), R6.2, R7.2, R8.2, R9.2, R10.2, R11.2, R25.2, U1.2 (GND), U2.1 (GND), U3.3 (GND), U4.2 (VSS), U4.8 (STBY), U6.1 (GND), U6.14 (IO12), U6.15 (GND), U6.38 (GND), U6.39 (GND), U7.25 (VSS)
unnamed: C14.2, C15.2, U7.6 (VDDCR)
unnamed: J1.3 (CANL), J1.4 (CANL), R12.1, U3.2 (CANL), U4.6 (CANL)
unnamed: J1.5 (CANH), J1.6 (CANH), R12.2, U3.1 (CANH), U4.7 (CANH)
unnamed: J2.2 (B1/SDA), R1.1
unnamed: J2.3 (B2/SCL), R3.1
unnamed: J2.4 (B3), R4.1
unnamed: J2.5 (B4), R5.1
unnamed: J3.L1 (LEDY_A), R8.1, U7.2 (LED2/nINTSEL)
unnamed: J3.L2 (LEDY_K), R11.1
unnamed: J3.L3 (LEDG_K), R10.1
unnamed: J3.L4 (LEDG_A), R9.1, U7.3 (LED1/REGOFF)
unnamed: J3.R1 (TD+), R20.2, U7.21 (TXP)
unnamed: J3.R2 (TD-), R21.2, U7.20 (TXN)
unnamed: J3.R3 (RD+), R22.2, U7.23 (RXP)
unnamed: J3.R6 (RD-), R23.2, U7.22 (RXN)
unnamed: J5.2 (B1/SDA), R24.1
unnamed: J5.3 (B2/SCL), R29.1
unnamed: J5.4 (B3), R30.1
unnamed: J5.5 (B4), R31.1
unnamed: R2.2, U7.8 (RXD0/MODE0)
unnamed: R7.1, U7.24 (RBIAS)
unnamed: R16.2, U7.7 (RXD1/MODE1)
unnamed: R19.1, U6.28 (IO17)
VDDA: C7.1, C8.1, C16.1, C17.1, C18.1, FB1.1, J3.R4 (TCT), J3.R5 (RCT), R20.1, R21.1, R22.1, R23.1, U7.1 (VDD2A), U7.9 (VDDIO), U7.19 (VDD1A)

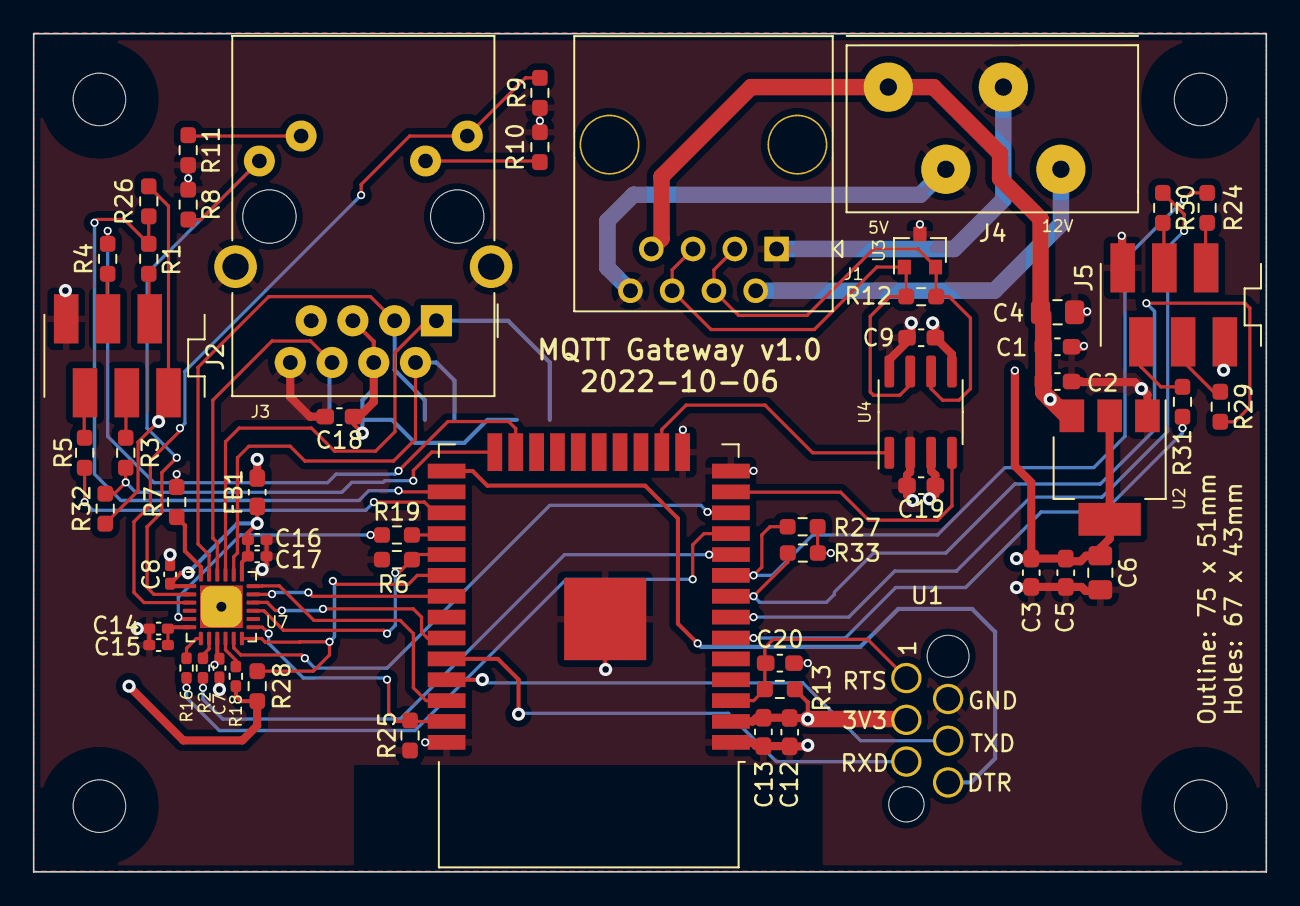
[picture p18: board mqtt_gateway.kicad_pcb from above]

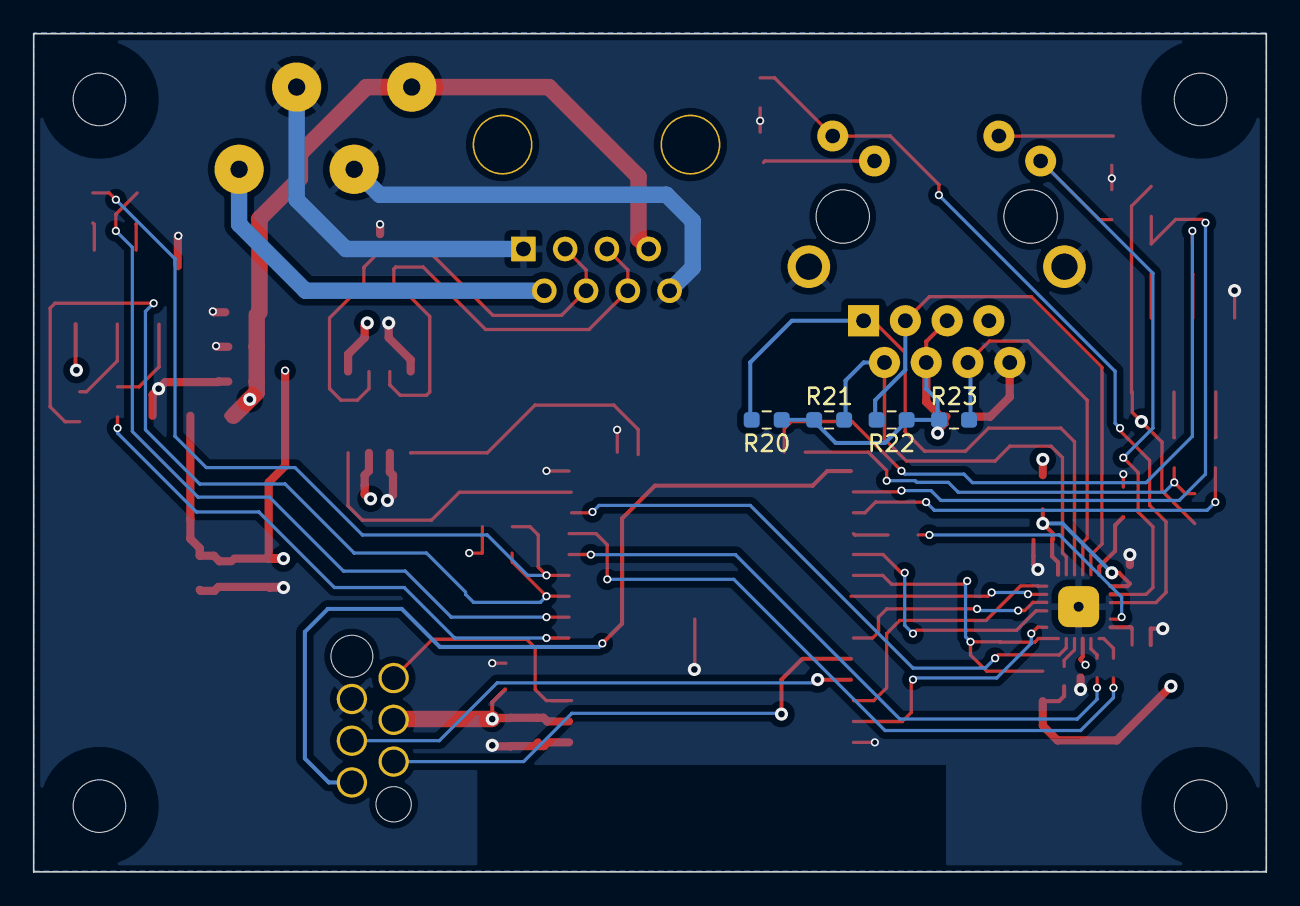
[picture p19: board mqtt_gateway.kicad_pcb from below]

Board: 4 copper layers, 75.0 x 51.0 mm, 64 parts (4 on the bottom side), 53 nets.

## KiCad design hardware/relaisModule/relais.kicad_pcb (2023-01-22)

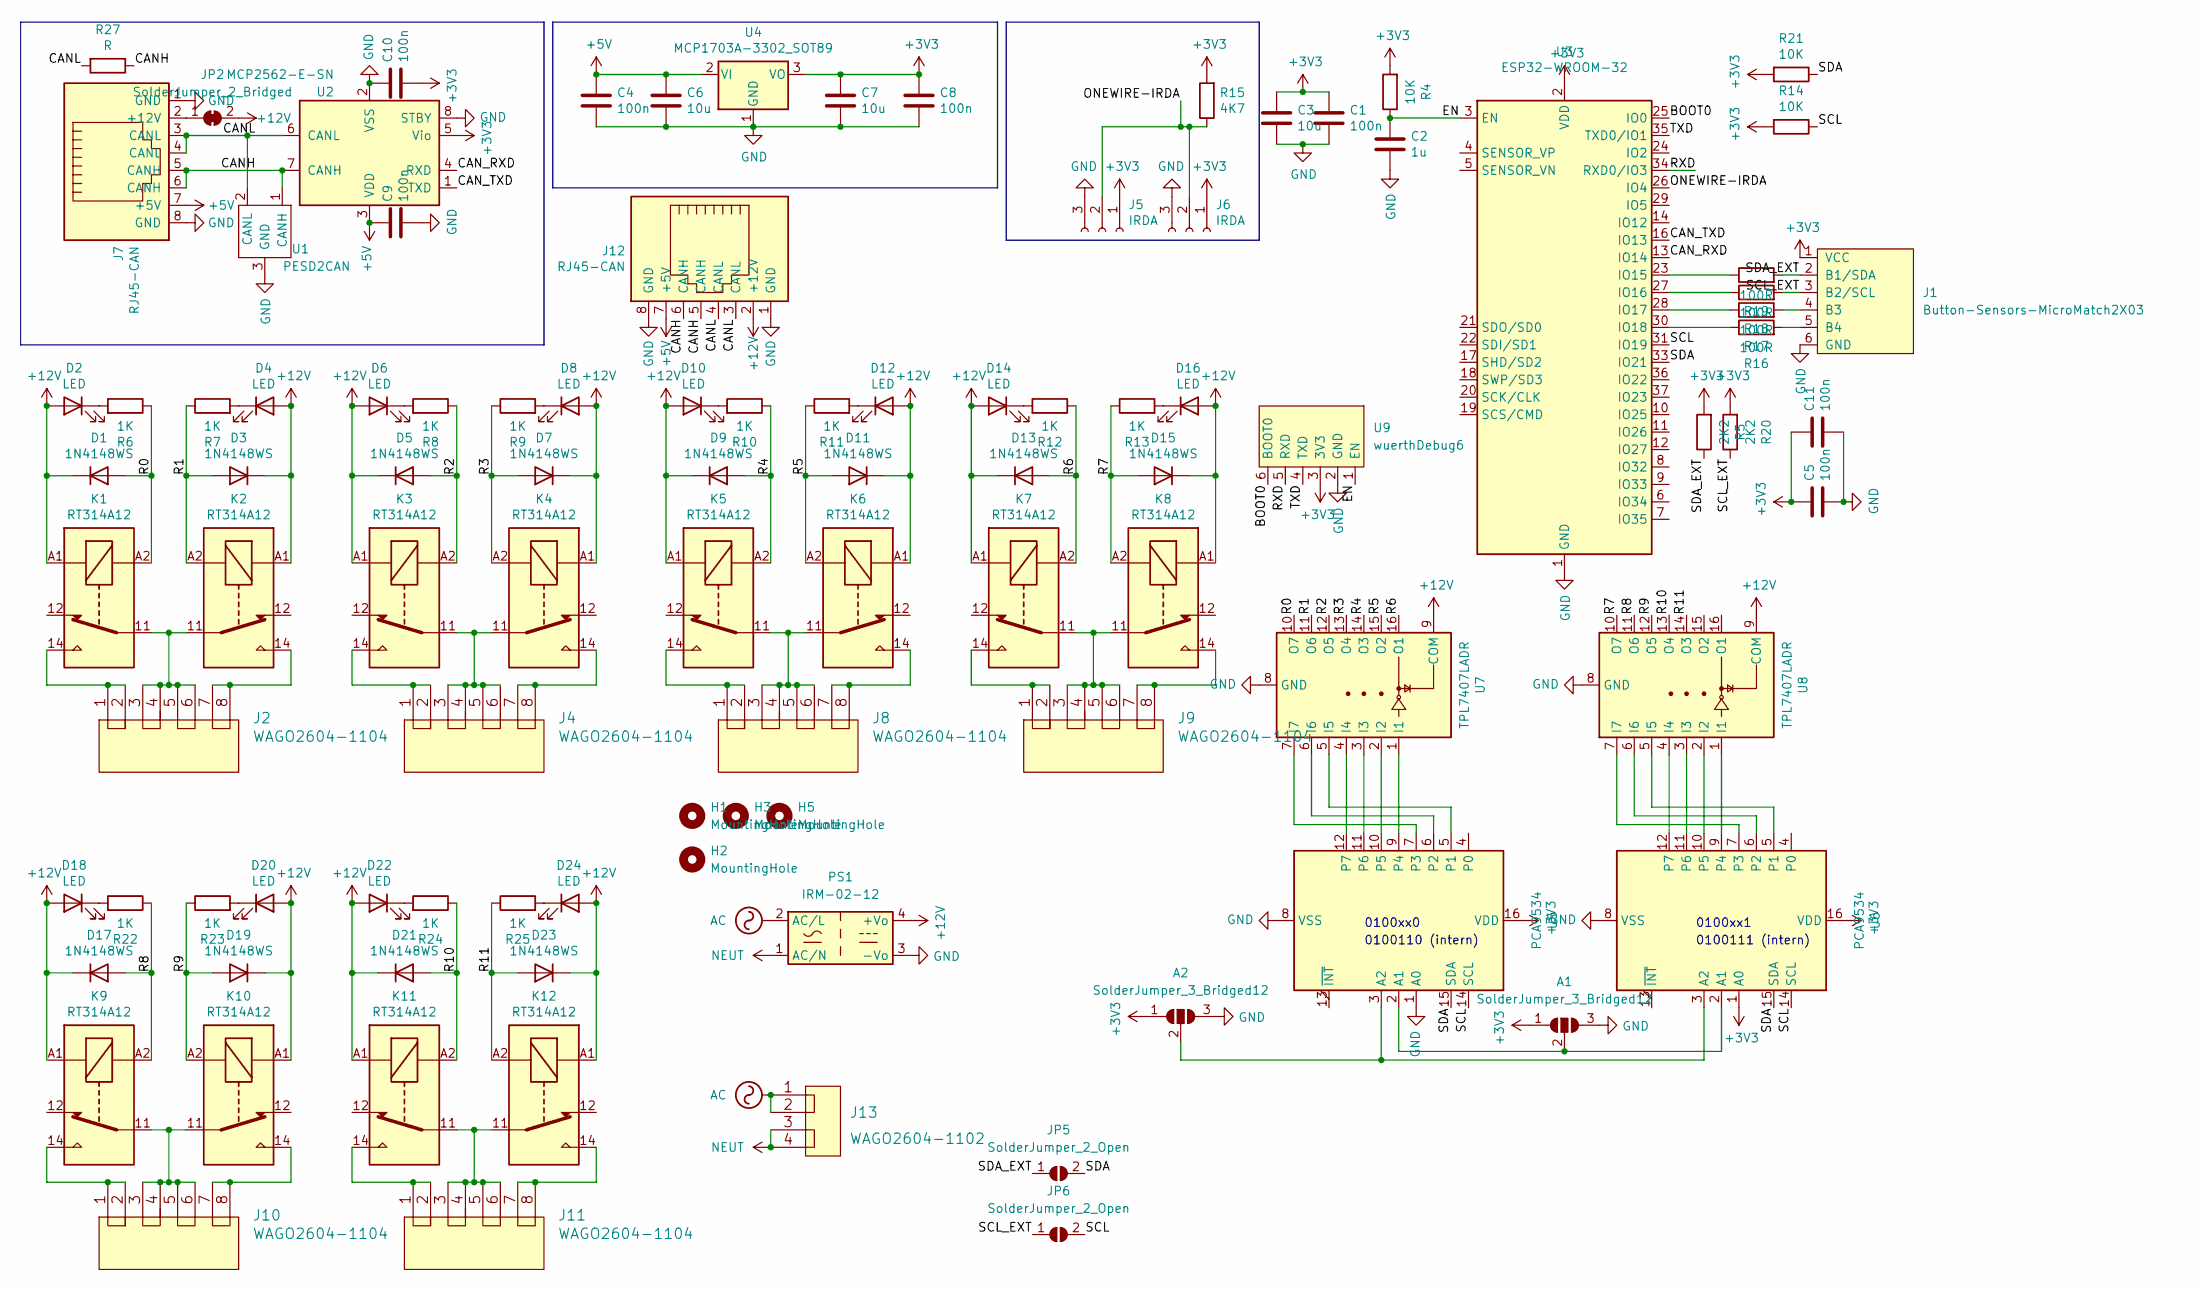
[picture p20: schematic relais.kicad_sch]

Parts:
A1, A2: SolderJumper_3_Bridged12; SolderJumper-3_P1.3mm_Open_RoundedPad1.0x1.5mm
C1, C4, C5, C8, C9, C10, C11: 100n; C_0603_1608Metric_Pad1.08x0.95mm_HandSolder
C2: 1u; C_0603_1608Metric_Pad1.08x0.95mm_HandSolder
C3, C6, C7: 10u; C_0805_2012Metric_Pad1.18x1.45mm_HandSolder
D1, D3, D5, D7, D9, D11, D13, D15, D17, D19, D21, D23: 1N4148WS; D_SOD-123
D2, D4, D6, D8, D10, D12, D14, D16, D18, D20, D22, D24: LED; LED_0603_1608Metric_Pad1.05x0.95mm_HandSolder
H1, H2, H3, H5: MountingHole; MountingHole_3.2mm_M3_DIN965
J1: Button-Sensors-MicroMatch2X03; 02x03MicroMatch
J2, J4, J8, J9, J10, J11: WAGO2604-1104
J5, J6: IRDA; PinHeader_1x03_P2.54mm_Vertical
J7, J12: RJ45-CAN; RJ45_OST_PJ012-8P8CX_Vertical
J13: WAGO2604-1102
JP2: SolderJumper_2_Bridged; SolderJumper-2_P1.3mm_Open_RoundedPad1.0x1.5mm
JP5, JP6: SolderJumper_2_Open; SolderJumper-2_P1.3mm_Open_RoundedPad1.0x1.5mm
K1, K2, K3, K4, K5, K6, K7, K8, K9, K10, K11, K12: RT314A12; Relay_SPDT_Schrack-RT1-16A-FormC_RM5mm
PS1: IRM-02-12; Converter_ACDC_MeanWell_IRM-02-xx_THT
R4, R14, R21: 10K; R_0603_1608Metric_Pad0.98x0.95mm_HandSolder
R5, R20: 2K2; R_0603_1608Metric_Pad0.98x0.95mm_HandSolder
R6, R7, R8, R9, R10, R11, R12, R13, R22, R23, R24, R25: 1K; R_0603_1608Metric_Pad0.98x0.95mm_HandSolder
R15: 4K7; R_0603_1608Metric_Pad0.98x0.95mm_HandSolder
R16, R17, R18, R19: 100R; R_0603_1608Metric_Pad0.98x0.95mm_HandSolder
R27: R; R_0603_1608Metric_Pad0.98x0.95mm_HandSolder
U1: PESD2CAN; SOT-23
U2: MCP2562-E-SN; SOIC-8_3.9x4.9mm_P1.27mm
U3: ESP32-WROOM-32
U4: MCP1703A-3302_SOT89; SOT-89-3_Handsoldering
U5, U6: PCA9534; SOIC-16W_7.5x10.3mm_P1.27mm
U7, U8: TPL7407LADR; SO-16_5.3x10.2mm_P1.27mm
U9: wuerthDebug6

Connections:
+3V3: A1.1 (A), A2.1 (A), C1.1, C3.1, C5.1, C7.1, C8.1, C10.1, C11.1, J1.1 (VCC), J5.1, J6.1, R4.2, R5.2, R14.2, R15.2, R20.2, R21.2, U2.5 (Vio), U3.2 (VDD), U4.3 (VO), U5.16 (VDD), U6.1 (A0), U6.16 (VDD), U9.3 (3V3)
+5V: C4.1, C6.1, C9.1, J7.7 (+5V), J12.7 (+5V), U2.3 (VDD), U4.2 (VI)
+12V: D1.1 (K), D2.2 (A), D3.1 (K), D4.2 (A), D5.1 (K), D6.2 (A), D7.1 (K), D8.2 (A), D9.1 (K), D10.2 (A), D11.1 (K), D12.2 (A), D13.1 (K), D14.2 (A), D15.1 (K), D16.2 (A), D17.1 (K), D18.2 (A), D19.1 (K), D20.2 (A), D21.1 (K), D22.2 (A), D23.1 (K), D24.2 (A), J12.2 (+12V), JP2.2 (B), K1.A1, K2.A1, K3.A1, K4.A1, K5.A1, K6.A1, K7.A1, K8.A1, K9.A1, K10.A1, K11.A1, K12.A1, PS1.4 (+Vo), U7.9 (COM), U8.9 (COM)
/BOOT0: U3.25 (IO0), U9.6 (BOOT0)
/CANH: J7.5 (CANH), J7.6 (CANH), J12.5 (CANH), J12.6 (CANH), R27.1, U1.1 (CANH), U2.7 (CANH)
/CANL: J7.3 (CANL), J7.4 (CANL), J12.3 (CANL), J12.4 (CANL), R27.2, U1.2 (CANL), U2.6 (CANL)
/CAN_RXD: U2.4 (RXD), U3.13 (IO14)
/CAN_TXD: U2.1 (TXD), U3.16 (IO13)
/EN: C2.1, R4.1, U3.3 (EN), U9.1 (EN)
/ONEWIRE-IRDA: J5.2, J6.2, R15.1, U3.26 (IO4)
/R0: D1.2 (A), K1.A2, R6.1, U7.10 (O7)
/R1: D3.2 (A), K2.A2, R7.1, U7.11 (O6)
/R2: D5.2 (A), K3.A2, R8.1, U7.12 (O5)
/R3: D7.2 (A), K4.A2, R9.1, U7.13 (O4)
/R4: D9.2 (A), K5.A2, R10.1, U7.14 (O3)
/R5: D11.2 (A), K6.A2, R11.1, U7.15 (O2)
/R6: D13.2 (A), K7.A2, R12.1, U7.16 (O1)
/R7: D15.2 (A), K8.A2, R13.1, U8.10 (O7)
/R8: D17.2 (A), K9.A2, R22.1, U8.11 (O6)
/R9: D19.2 (A), K10.A2, R23.1, U8.12 (O5)
/R10: D21.2 (A), K11.A2, R24.1, U8.13 (O4)
/R11: D23.2 (A), K12.A2, R25.1, U8.14 (O3)
/RXD: U3.34 (RXD0/IO3), U9.5 (RXD)
/SCL: JP6.2 (B), R14.1, U3.31 (IO19), U5.14 (SCL), U6.14 (SCL)
/SCL_EXT: J1.3 (B2/SCL), JP6.1 (A), R18.2, R20.1
/SDA: JP5.2 (B), R21.1, U3.33 (IO21), U5.15 (SDA), U6.15 (SDA)
/SDA_EXT: J1.2 (B1/SDA), JP5.1 (A), R5.1, R19.2
/TXD: U3.35 (TXD0/IO1), U9.4 (TXD)
AC: J13.1, J13.2, PS1.2 (AC/L)
GND: A1.3 (B), A2.3 (B), C1.2, C2.2, C3.2, C4.2, C5.2, C6.2, C7.2, C8.2, C9.2, C10.2, C11.2, J1.6 (GND), J5.3, J6.3, J7.1 (GND), J7.8 (GND), J12.1 (GND), J12.8 (GND), PS1.3 (-Vo), U1.3 (GND), U2.2 (VSS), U2.8 (STBY), U3.1 (GND), U3.15 (GND), U3.38 (GND), U3.39 (GND), U4.1 (GND), U5.1 (A0), U5.8 (VSS), U6.8 (VSS), U7.8 (GND), U8.8 (GND), U9.2 (GND)
NEUT: J13.3, J13.4, PS1.1 (AC/N)
unnamed: A1.2 (C), U5.2 (A1), U6.2 (A1)
unnamed: A2.2 (C), U5.3 (A2), U6.3 (A2)
unnamed: D2.1 (K), R6.2
unnamed: D4.1 (K), R7.2
unnamed: D6.1 (K), R8.2
unnamed: D8.1 (K), R9.2
unnamed: D10.1 (K), R10.2
unnamed: D12.1 (K), R11.2
unnamed: D14.1 (K), R12.2
unnamed: D16.1 (K), R13.2
unnamed: D18.1 (K), R22.2
unnamed: D20.1 (K), R23.2
unnamed: D22.1 (K), R24.2
unnamed: D24.1 (K), R25.2
unnamed: J1.4 (B3), R17.2
unnamed: J1.5 (B4), R16.2
unnamed: J2.1, J2.2, K1.14
unnamed: J2.3, J2.4, J2.5, J2.6, K1.11, K2.11
unnamed: J2.7, J2.8, K2.14
unnamed: J4.1, J4.2, K3.14
unnamed: J4.3, J4.4, J4.5, J4.6, K3.11, K4.11
unnamed: J4.7, J4.8, K4.14
unnamed: J7.2 (+12V), JP2.1 (A)
unnamed: J8.1, J8.2, K5.14
unnamed: J8.3, J8.4, J8.5, J8.6, K5.11, K6.11
unnamed: J8.7, J8.8, K6.14
unnamed: J9.1, J9.2, K7.14
unnamed: J9.3, J9.4, J9.5, J9.6, K7.11, K8.11
unnamed: J9.7, J9.8, K8.14
unnamed: J10.1, J10.2, K9.14
unnamed: J10.3, J10.4, J10.5, J10.6, K9.11, K10.11
unnamed: J10.7, J10.8, K10.14
unnamed: J11.1, J11.2, K11.14
unnamed: J11.3, J11.4, J11.5, J11.6, K11.11, K12.11
unnamed: J11.7, J11.8, K12.14
unnamed: R16.1, U3.30 (IO18)
unnamed: R17.1, U3.28 (IO17)
unnamed: R18.1, U3.27 (IO16)
unnamed: R19.1, U3.23 (IO15)
unnamed: U5.5 (P1), U7.5 (I5)
unnamed: U5.6 (P2), U7.6 (I6)
unnamed: U5.7 (P3), U7.7 (I7)
unnamed: U5.9 (P4), U7.1 (I1)
unnamed: U5.10 (P5), U7.2 (I2)
unnamed: U5.11 (P6), U7.3 (I3)
unnamed: U5.12 (P7), U7.4 (I4)
unnamed: U6.5 (P1), U8.5 (I5)
unnamed: U6.6 (P2), U8.6 (I6)
unnamed: U6.7 (P3), U8.7 (I7)
unnamed: U6.9 (P4), U8.1 (I1)
unnamed: U6.10 (P5), U8.2 (I2)
unnamed: U6.11 (P6), U8.3 (I3)
unnamed: U6.12 (P7), U8.4 (I4)

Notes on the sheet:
0100110 (intern)
0100111 (intern)
0100xx0
0100xx1

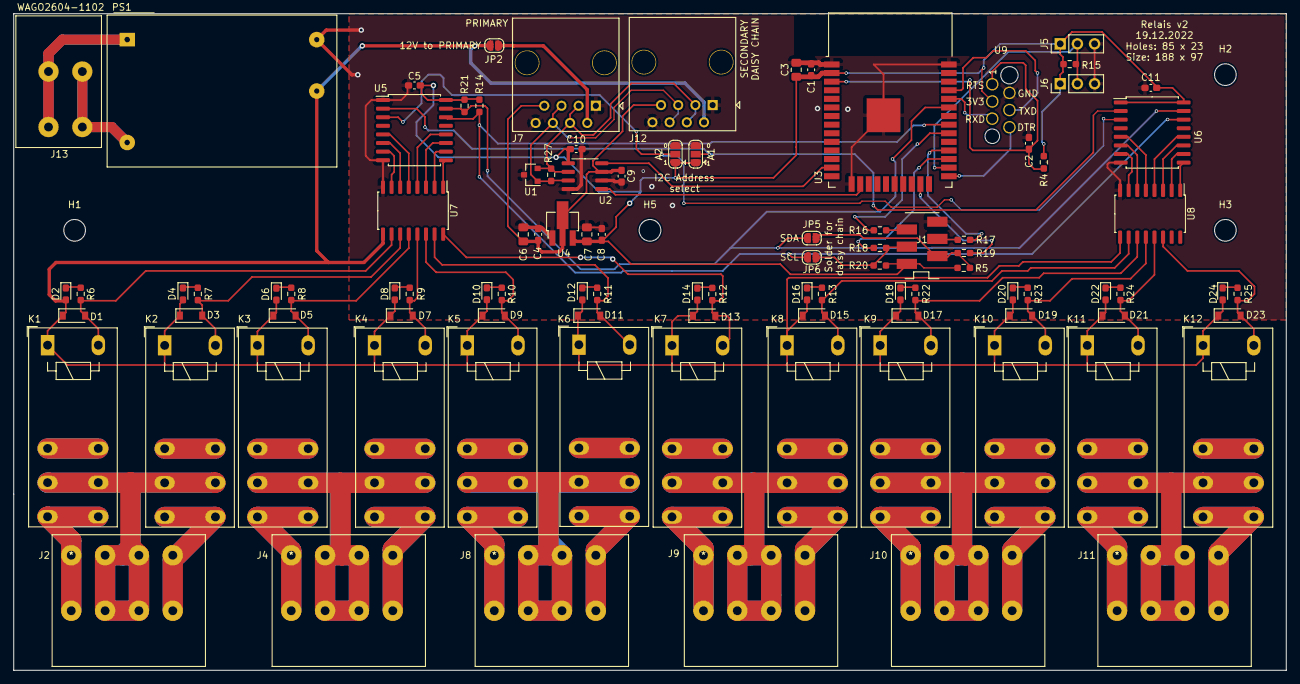
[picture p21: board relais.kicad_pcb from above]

Board: 2 copper layers, 188.0 x 97.0 mm, 101 parts (0 on the bottom side), 84 nets.

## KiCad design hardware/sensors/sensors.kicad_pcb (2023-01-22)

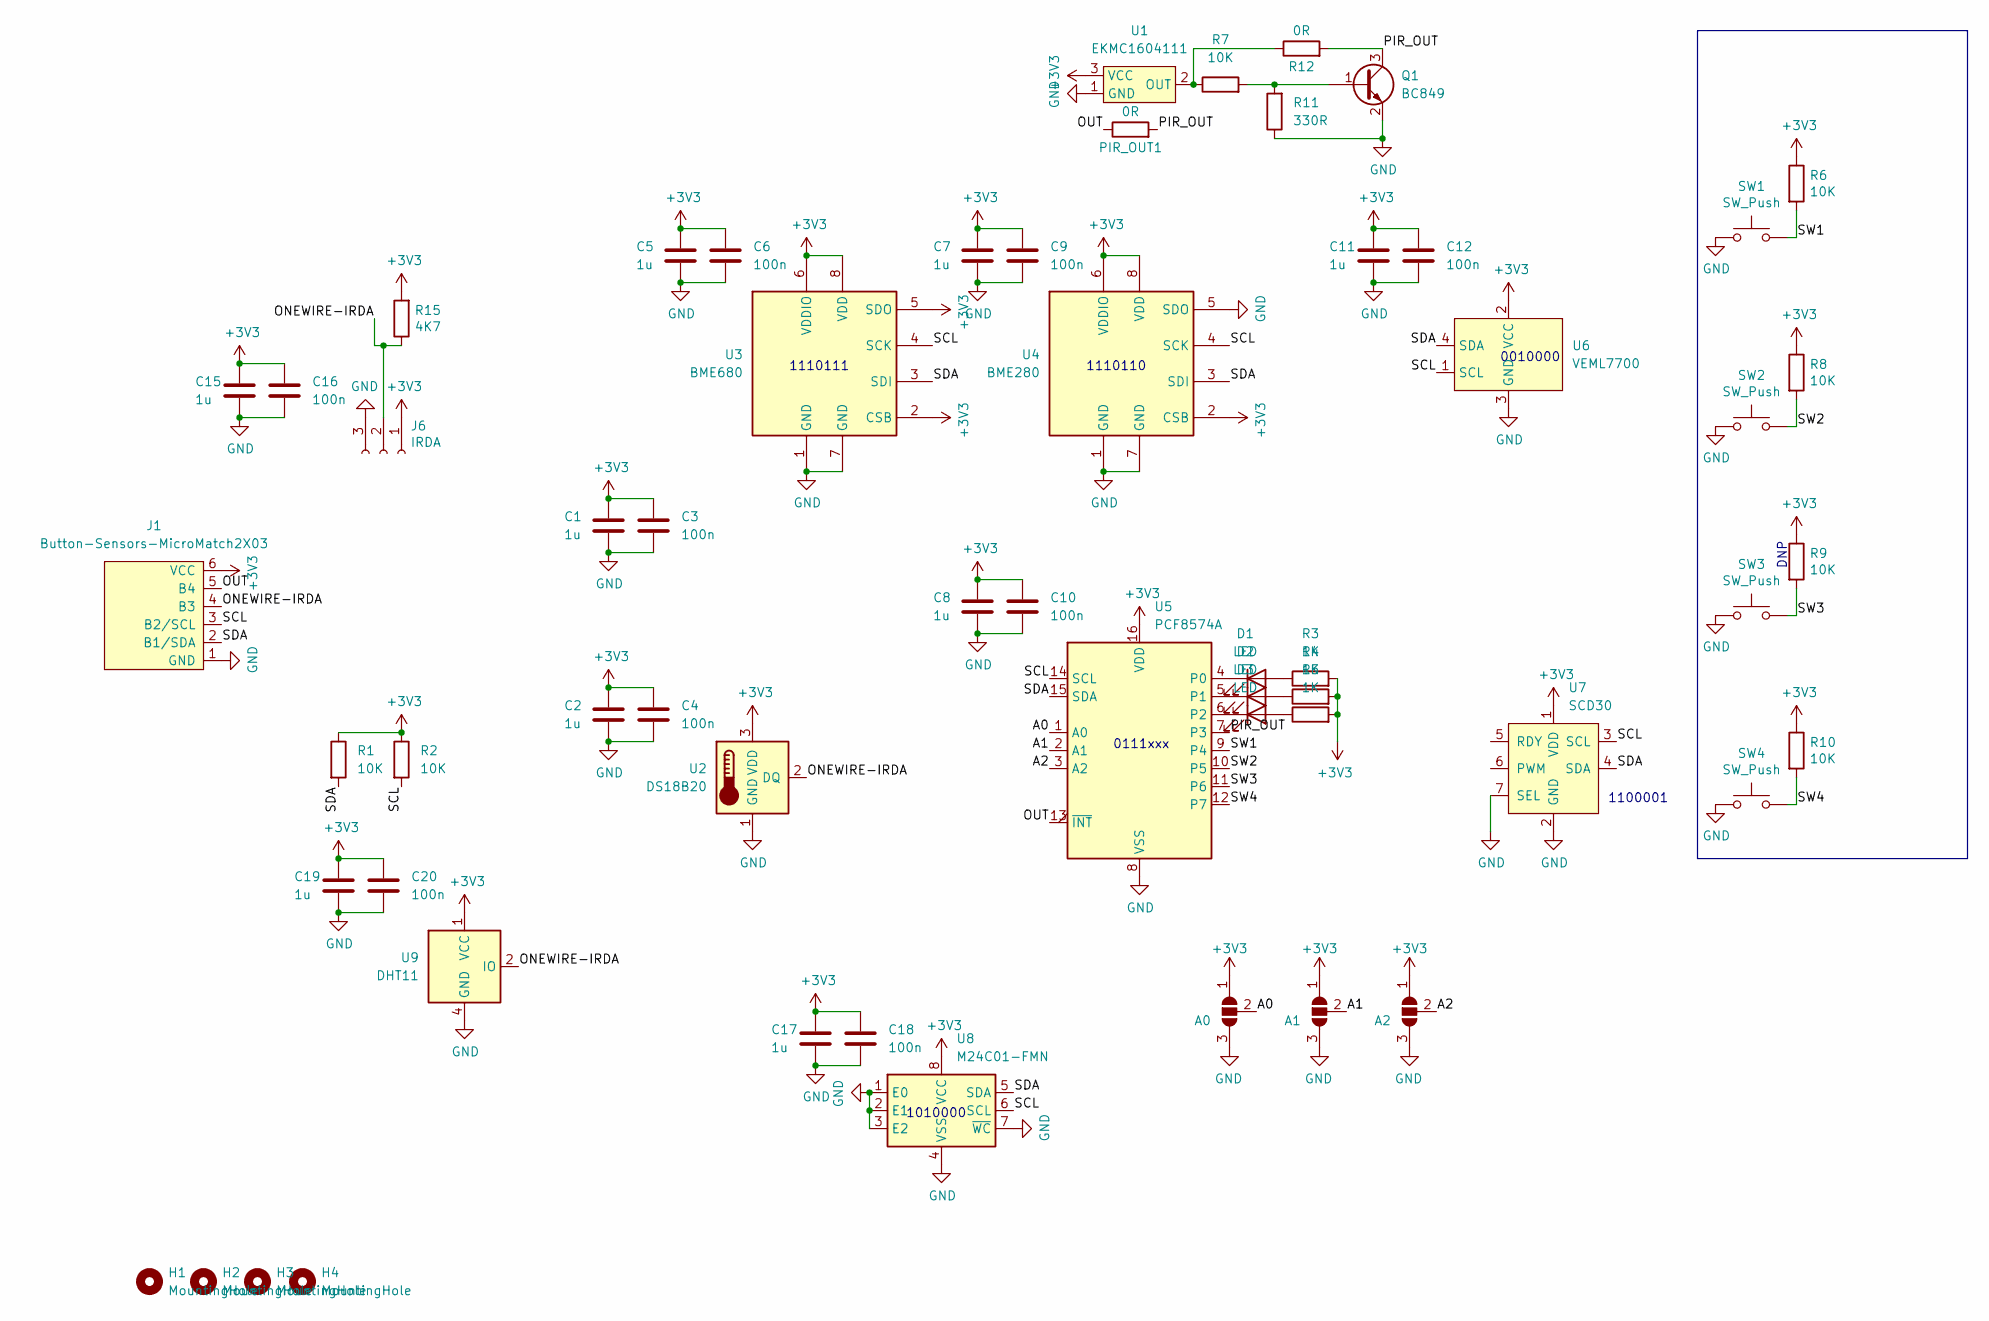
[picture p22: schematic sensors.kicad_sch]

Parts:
A0, A1, A2: SolderJumper_3_Open; SolderJumper-3_P1.3mm_Open_RoundedPad1.0x1.5mm
C1, C2, C5, C7, C8, C11, C15, C17, C19: 1u; C_0603_1608Metric_Pad1.08x0.95mm_HandSolder
C3, C4, C6, C9, C10, C12, C16, C18, C20: 100n; C_0603_1608Metric_Pad1.08x0.95mm_HandSolder
D1, D2, D3: LED; LED_0805_2012Metric_Pad1.15x1.40mm_HandSolder
H1, H2, H3, H4: MountingHole; MountingHole_2.2mm_M2
J1: Button-Sensors-MicroMatch2X03; 02x03MicroMatch
J6: IRDA; PinHeader_1x03_P2.54mm_Vertical
PIR_OUT1: 0R; SolderJumper-2_P1.3mm_Open_RoundedPad1.0x1.5mm
Q1: BC849; SOT-23
R1, R2, R6, R7, R8, R9, R10: 10K; R_0603_1608Metric_Pad0.98x0.95mm_HandSolder
R3, R4, R5: 1K; R_0603_1608Metric_Pad0.98x0.95mm_HandSolder
R11: 330R; R_0603_1608Metric_Pad0.98x0.95mm_HandSolder
R12: 0R; SolderJumper-2_P1.3mm_Open_RoundedPad1.0x1.5mm
R15: 4K7; R_0603_1608Metric_Pad0.98x0.95mm_HandSolder
SW1, SW2, SW3, SW4: SW_Push; SW_SPST_TL3305A
U1: EKMC1604111
U2: DS18B20; TO-92_Inline
U3: BME680; Bosch_LGA-8
U4: BME280; Bosch_LGA-8
U5: PCF8574A; SOIC-16W_7.5x10.3mm_P1.27mm
U6: VEML7700
U7: SCD30
U8: M24C01-FMN; SOIC-8_3.9x4.9mm_P1.27mm
U9: DHT11; Aosong_DHT11_5.5x12.0_P2.54mm

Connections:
+3V3: A0.1 (A), A1.1 (A), A2.1 (A), C1.1, C2.1, C3.1, C4.1, C5.1, C6.1, C7.1, C8.1, C9.1, C10.1, C11.1, C12.1, C15.1, C16.1, C17.1, C18.1, C19.1, C20.1, J1.6 (VCC), J6.1, R1.1, R2.1, R3.2, R4.2, R5.2, R6.1, R8.1, R9.1, R10.1, R15.2, U1.3 (VCC), U2.3 (VDD), U3.2 (CSB), U3.5 (SDO), U3.6 (VDDIO), U3.8 (VDD), U4.2 (CSB), U4.6 (VDDIO), U4.8 (VDD), U5.16 (VDD), U6.2 (VCC), U7.1 (VDD), U8.8 (VCC), U9.1 (VCC)
/A0: A0.2 (C), U5.1 (A0)
/A1: A1.2 (C), U5.2 (A1)
/A2: A2.2 (C), U5.3 (A2)
/ONEWIRE-IRDA: J1.4 (B3), J6.2, R15.1, U2.2 (DQ), U9.2 (IO)
/OUT: J1.5 (B4), PIR_OUT1.1, U5.13 (~INT)
/PIR_OUT: PIR_OUT1.2, Q1.3 (C), R12.2, U5.7 (P3)
/SCL: J1.3 (B2/SCL), R2.2, U3.4 (SCK), U4.4 (SCK), U5.14 (SCL), U6.1 (SCL), U7.3 (SCL), U8.6 (SCL)
/SDA: J1.2 (B1/SDA), R1.2, U3.3 (SDI), U4.3 (SDI), U5.15 (SDA), U6.4 (SDA), U7.4 (SDA), U8.5 (SDA)
/SW1: R6.2, SW1.2, U5.9 (P4)
/SW2: R8.2, SW2.2, U5.10 (P5)
/SW3: R9.2, SW3.2, U5.11 (P6)
/SW4: R10.2, SW4.2, U5.12 (P7)
GND: A0.3 (B), A1.3 (B), A2.3 (B), C1.2, C2.2, C3.2, C4.2, C5.2, C6.2, C7.2, C8.2, C9.2, C10.2, C11.2, C12.2, C15.2, C16.2, C17.2, C18.2, C19.2, C20.2, J1.1 (GND), J6.3, Q1.2 (E), R11.1, SW1.1, SW2.1, SW3.1, SW4.1, U1.1 (GND), U2.1 (GND), U3.1 (GND), U3.7 (GND), U4.1 (GND), U4.5 (SDO), U4.7 (GND), U5.8 (VSS), U6.3 (GND), U7.2 (GND), U7.7 (SEL), U8.1 (E0), U8.2 (E1), U8.3 (E2), U8.4 (VSS), U8.7 (~WC), U9.4 (GND)
unnamed: D1.1 (K), U5.4 (P0)
unnamed: D1.2 (A), R3.1
unnamed: D2.1 (K), U5.5 (P1)
unnamed: D2.2 (A), R4.1
unnamed: D3.1 (K), U5.6 (P2)
unnamed: D3.2 (A), R5.1
unnamed: Q1.1 (B), R7.2, R11.2
unnamed: R7.1, R12.1, U1.2 (OUT)

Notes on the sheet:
0111xxx
1100001
1110110
DNP
1010000
0010000
1110111

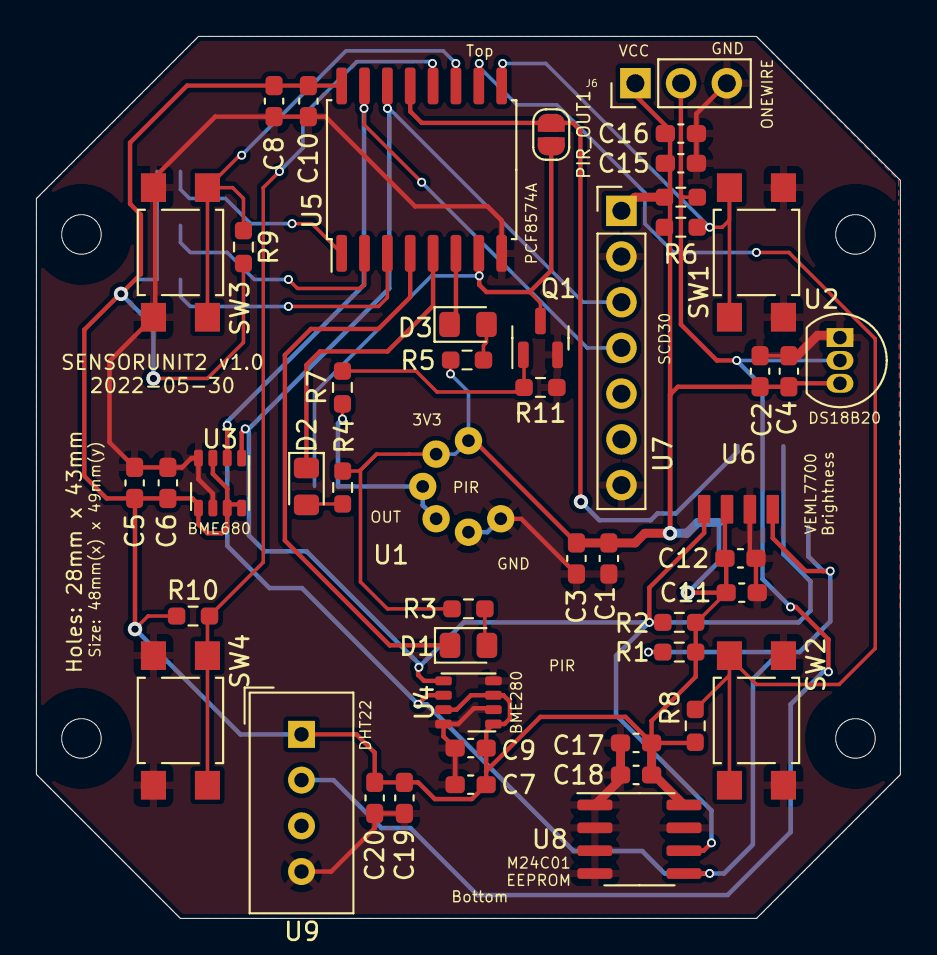
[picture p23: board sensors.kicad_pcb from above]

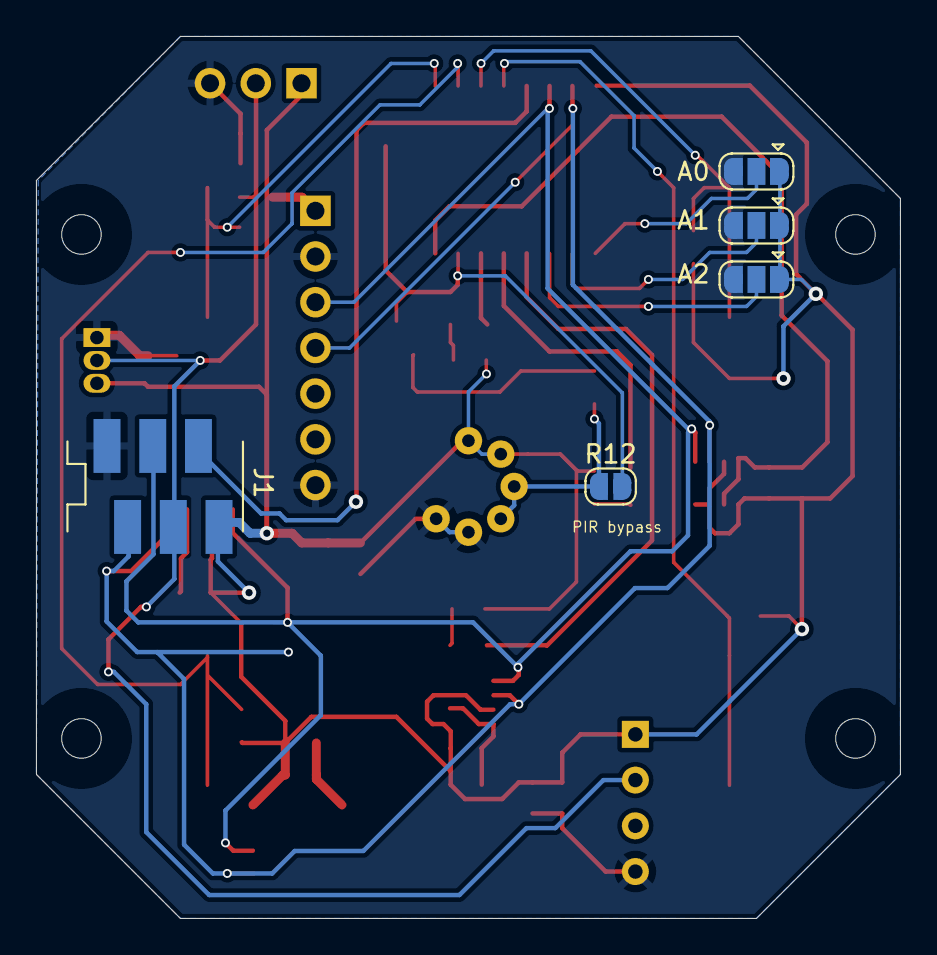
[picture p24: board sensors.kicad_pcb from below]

Board: 2 copper layers, 48.0 x 49.0 mm, 58 parts (5 on the bottom side), 22 nets.

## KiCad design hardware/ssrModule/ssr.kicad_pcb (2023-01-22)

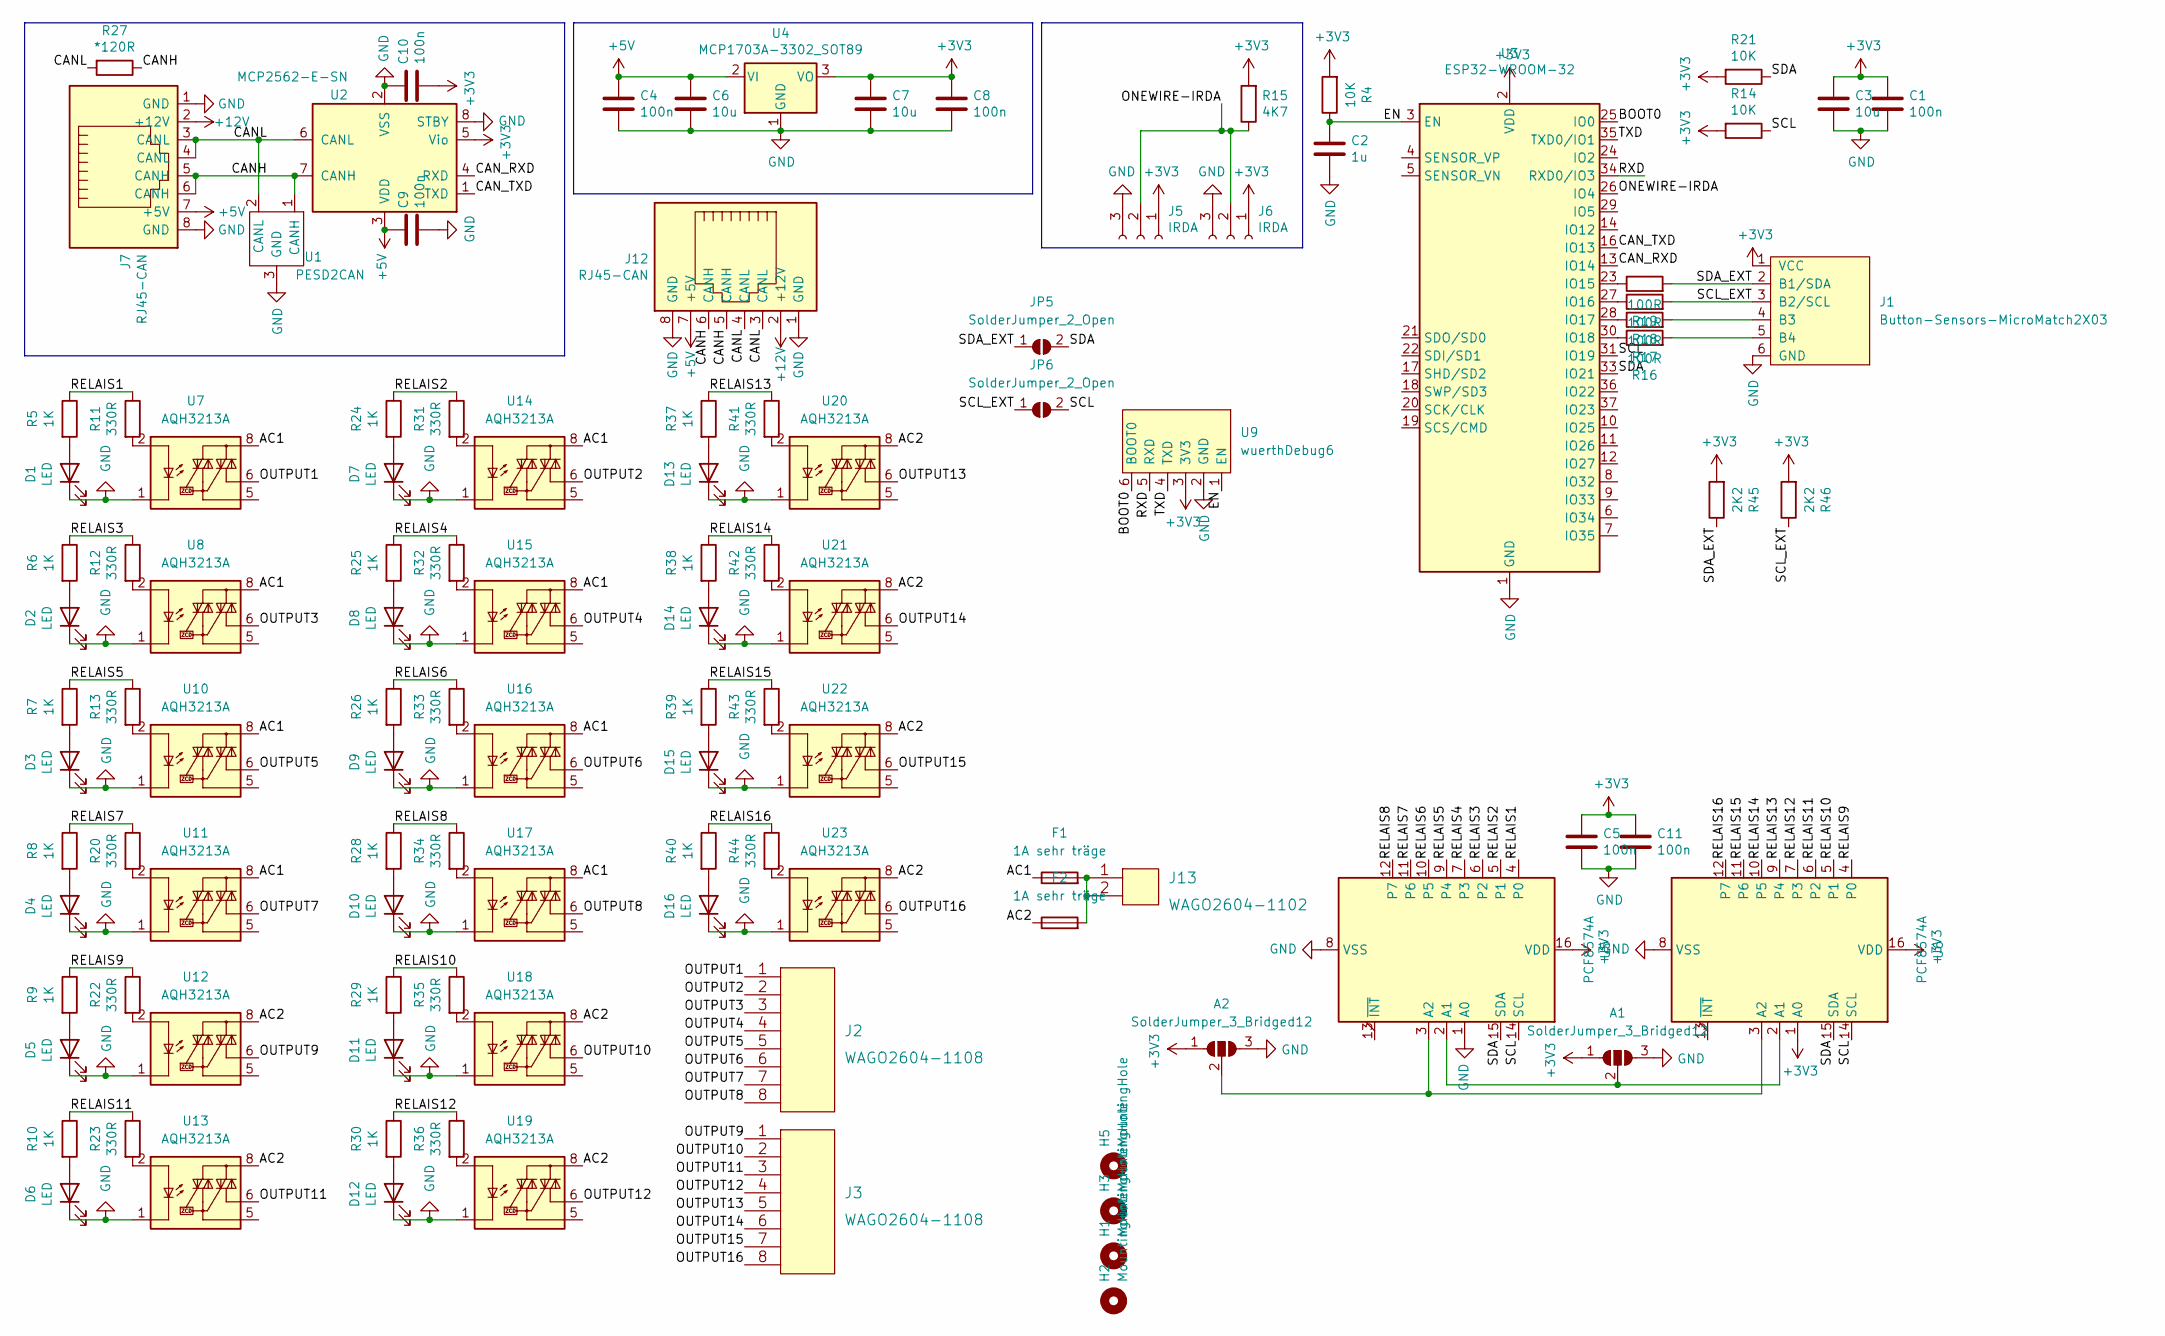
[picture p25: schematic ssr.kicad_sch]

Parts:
A1, A2: SolderJumper_3_Bridged12; SolderJumper-3_P1.3mm_Open_RoundedPad1.0x1.5mm
C1, C4, C5, C8, C9, C10, C11: 100n; C_0603_1608Metric_Pad1.08x0.95mm_HandSolder
C2: 1u; C_0603_1608Metric_Pad1.08x0.95mm_HandSolder
C3, C6, C7: 10u; C_0805_2012Metric_Pad1.18x1.45mm_HandSolder
D1, D2, D3, D4, D5, D6, D7, D8, D9, D10, D11, D12, D13, D14, D15, D16: LED; LED_0603_1608Metric_Pad1.05x0.95mm_HandSolder
F1, F2: 1A sehr träge; Fuseholder_Cylinder-5x20mm_Schurter_0031_8201_Horizontal_Op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
H1, H2, H3, H5: MountingHole; MountingHole_3.2mm_M3_DIN965
J1: Button-Sensors-MicroMatch2X03; 02x03MicroMatch
J2, J3: WAGO2604-1108
J5, J6: IRDA; PinHeader_1x03_P2.54mm_Vertical
J7, J12: RJ45-CAN; RJ45_OST_PJ012-8P8CX_Vertical
J13: WAGO2604-1102
JP5, JP6: SolderJumper_2_Open; SolderJumper-2_P1.3mm_Open_RoundedPad1.0x1.5mm
R4, R14, R21: 10K; R_0603_1608Metric_Pad0.98x0.95mm_HandSolder
R5, R6, R7, R8, R9, R10, R24, R25, R26, R28, R29, R30, R37, R38, R39, R40: 1K; R_0603_1608Metric_Pad0.98x0.95mm_HandSolder
R11, R12, R13, R20, R22, R23, R31, R32, R33, R34, R35, R36, R41, R42, R43, R44: 330R; R_0603_1608Metric_Pad0.98x0.95mm_HandSolder
R15: 4K7; R_0603_1608Metric_Pad0.98x0.95mm_HandSolder
R16, R17, R18, R19: 100R; R_0603_1608Metric_Pad0.98x0.95mm_HandSolder
R27: *120R; R_0603_1608Metric_Pad0.98x0.95mm_HandSolder
R45, R46: 2K2; R_0603_1608Metric_Pad0.98x0.95mm_HandSolder
U1: PESD2CAN; SOT-23
U2: MCP2562-E-SN; SOIC-8_3.9x4.9mm_P1.27mm
U3: ESP32-WROOM-32
U4: MCP1703A-3302_SOT89; SOT-89-3_Handsoldering
U5, U6: PCF8574A; SOIC-16W_7.5x10.3mm_P1.27mm
U7, U8, U10, U11, U12, U13, U14, U15, U16, U17, U18, U19, U20, U21, U22, U23: AQH3213A; SSO-7-8_6.4x9.78mm_P2.54mm
U9: wuerthDebug6

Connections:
+3V3: A1.1 (A), A2.1 (A), C1.1, C3.1, C5.1, C7.1, C8.1, C10.1, C11.1, J1.1 (VCC), J5.1, J6.1, R4.2, R14.2, R15.2, R21.2, R45.2, R46.2, U2.5 (Vio), U3.2 (VDD), U4.3 (VO), U5.16 (VDD), U6.1 (A0), U6.16 (VDD), U9.3 (3V3)
+5V: C4.1, C6.1, C9.1, J7.7 (+5V), J12.7 (+5V), U2.3 (VDD), U4.2 (VI)
+12V: J7.2 (+12V), J12.2 (+12V)
/AC1: F1.1, U7.8, U8.8, U10.8, U11.8, U14.8, U15.8, U16.8, U17.8
/AC2: F2.1, U12.8, U13.8, U18.8, U19.8, U20.8, U21.8, U22.8, U23.8
/BOOT0: U3.25 (IO0), U9.6 (BOOT0)
/CANH: J7.5 (CANH), J7.6 (CANH), J12.5 (CANH), J12.6 (CANH), R27.1, U1.1 (CANH), U2.7 (CANH)
/CANL: J7.3 (CANL), J7.4 (CANL), J12.3 (CANL), J12.4 (CANL), R27.2, U1.2 (CANL), U2.6 (CANL)
/CAN_RXD: U2.4 (RXD), U3.13 (IO14)
/CAN_TXD: U2.1 (TXD), U3.16 (IO13)
/EN: C2.1, R4.1, U3.3 (EN), U9.1 (EN)
/ONEWIRE-IRDA: J5.2, J6.2, R15.1, U3.26 (IO4)
/OUTPUT1: J2.1, U7.6
/OUTPUT2: J2.2, U14.6
/OUTPUT3: J2.3, U8.6
/OUTPUT4: J2.4, U15.6
/OUTPUT5: J2.5, U10.6
/OUTPUT6: J2.6, U16.6
/OUTPUT7: J2.7, U11.6
/OUTPUT8: J2.8, U17.6
/OUTPUT9: J3.1, U12.6
/OUTPUT10: J3.2, U18.6
/OUTPUT11: J3.3, U13.6
/OUTPUT12: J3.4, U19.6
/OUTPUT13: J3.5, U20.6
/OUTPUT14: J3.6, U21.6
/OUTPUT15: J3.7, U22.6
/OUTPUT16: J3.8, U23.6
/RELAIS1: R5.1, R11.1, U5.4 (P0)
/RELAIS2: R24.1, R31.1, U5.5 (P1)
/RELAIS3: R6.1, R12.1, U5.6 (P2)
/RELAIS4: R25.1, R32.1, U5.7 (P3)
/RELAIS5: R7.1, R13.1, U5.9 (P4)
/RELAIS6: R26.1, R33.1, U5.10 (P5)
/RELAIS7: R8.1, R20.1, U5.11 (P6)
/RELAIS8: R28.1, R34.1, U5.12 (P7)
/RELAIS9: R9.1, R22.1, U6.4 (P0)
/RELAIS10: R29.1, R35.1, U6.5 (P1)
/RELAIS11: R10.1, R23.1, U6.6 (P2)
/RELAIS12: R30.1, R36.1, U6.7 (P3)
/RELAIS13: R37.1, R41.1, U6.9 (P4)
/RELAIS14: R38.1, R42.1, U6.10 (P5)
/RELAIS15: R39.1, R43.1, U6.11 (P6)
/RELAIS16: R40.1, R44.1, U6.12 (P7)
/RXD: U3.34 (RXD0/IO3), U9.5 (RXD)
/SCL: JP6.2 (B), R14.1, U3.31 (IO19), U5.14 (SCL), U6.14 (SCL)
/SCL_EXT: J1.3 (B2/SCL), JP6.1 (A), R18.2, R46.1
/SDA: JP5.2 (B), R21.1, U3.33 (IO21), U5.15 (SDA), U6.15 (SDA)
/SDA_EXT: J1.2 (B1/SDA), JP5.1 (A), R19.2, R45.1
/TXD: U3.35 (TXD0/IO1), U9.4 (TXD)
GND: A1.3 (B), A2.3 (B), C1.2, C2.2, C3.2, C4.2, C5.2, C6.2, C7.2, C8.2, C9.2, C10.2, C11.2, D1.1 (K), D2.1 (K), D3.1 (K), D4.1 (K), D5.1 (K), D6.1 (K), D7.1 (K), D8.1 (K), D9.1 (K), D10.1 (K), D11.1 (K), D12.1 (K), D13.1 (K), D14.1 (K), D15.1 (K), D16.1 (K), J1.6 (GND), J5.3, J6.3, J7.1 (GND), J7.8 (GND), J12.1 (GND), J12.8 (GND), U1.3 (GND), U2.2 (VSS), U2.8 (STBY), U3.1 (GND), U3.15 (GND), U3.38 (GND), U3.39 (GND), U4.1 (GND), U5.1 (A0), U5.8 (VSS), U6.8 (VSS), U7.1, U7.3, U7.4, U8.1, U8.3, U8.4, U9.2 (GND), U10.1, U10.3, U10.4, U11.1, U11.3, U11.4, U12.1, U12.3, U12.4, U13.1, U13.3, U13.4, U14.1, U14.3, U14.4, U15.1, U15.3, U15.4, U16.1, U16.3, U16.4, U17.1, U17.3, U17.4, U18.1, U18.3, U18.4, U19.1, U19.3, U19.4, U20.1, U20.3, U20.4, U21.1, U21.3, U21.4, U22.1, U22.3, U22.4, U23.1, U23.3, U23.4
unnamed: A1.2 (C), U5.2 (A1), U6.2 (A1)
unnamed: A2.2 (C), U5.3 (A2), U6.3 (A2)
unnamed: D1.2 (A), R5.2
unnamed: D2.2 (A), R6.2
unnamed: D3.2 (A), R7.2
unnamed: D4.2 (A), R8.2
unnamed: D5.2 (A), R9.2
unnamed: D6.2 (A), R10.2
unnamed: D7.2 (A), R24.2
unnamed: D8.2 (A), R25.2
unnamed: D9.2 (A), R26.2
unnamed: D10.2 (A), R28.2
unnamed: D11.2 (A), R29.2
unnamed: D12.2 (A), R30.2
unnamed: D13.2 (A), R37.2
unnamed: D14.2 (A), R38.2
unnamed: D15.2 (A), R39.2
unnamed: D16.2 (A), R40.2
unnamed: F1.2, F2.2, J13.1, J13.2
unnamed: J1.4 (B3), R17.2
unnamed: J1.5 (B4), R16.2
unnamed: R11.2, U7.2
unnamed: R12.2, U8.2
unnamed: R13.2, U10.2
unnamed: R16.1, U3.30 (IO18)
unnamed: R17.1, U3.28 (IO17)
unnamed: R18.1, U3.27 (IO16)
unnamed: R19.1, U3.23 (IO15)
unnamed: R20.2, U11.2
unnamed: R22.2, U12.2
unnamed: R23.2, U13.2
unnamed: R31.2, U14.2
unnamed: R32.2, U15.2
unnamed: R33.2, U16.2
unnamed: R34.2, U17.2
unnamed: R35.2, U18.2
unnamed: R36.2, U19.2
unnamed: R41.2, U20.2
unnamed: R42.2, U21.2
unnamed: R43.2, U22.2
unnamed: R44.2, U23.2

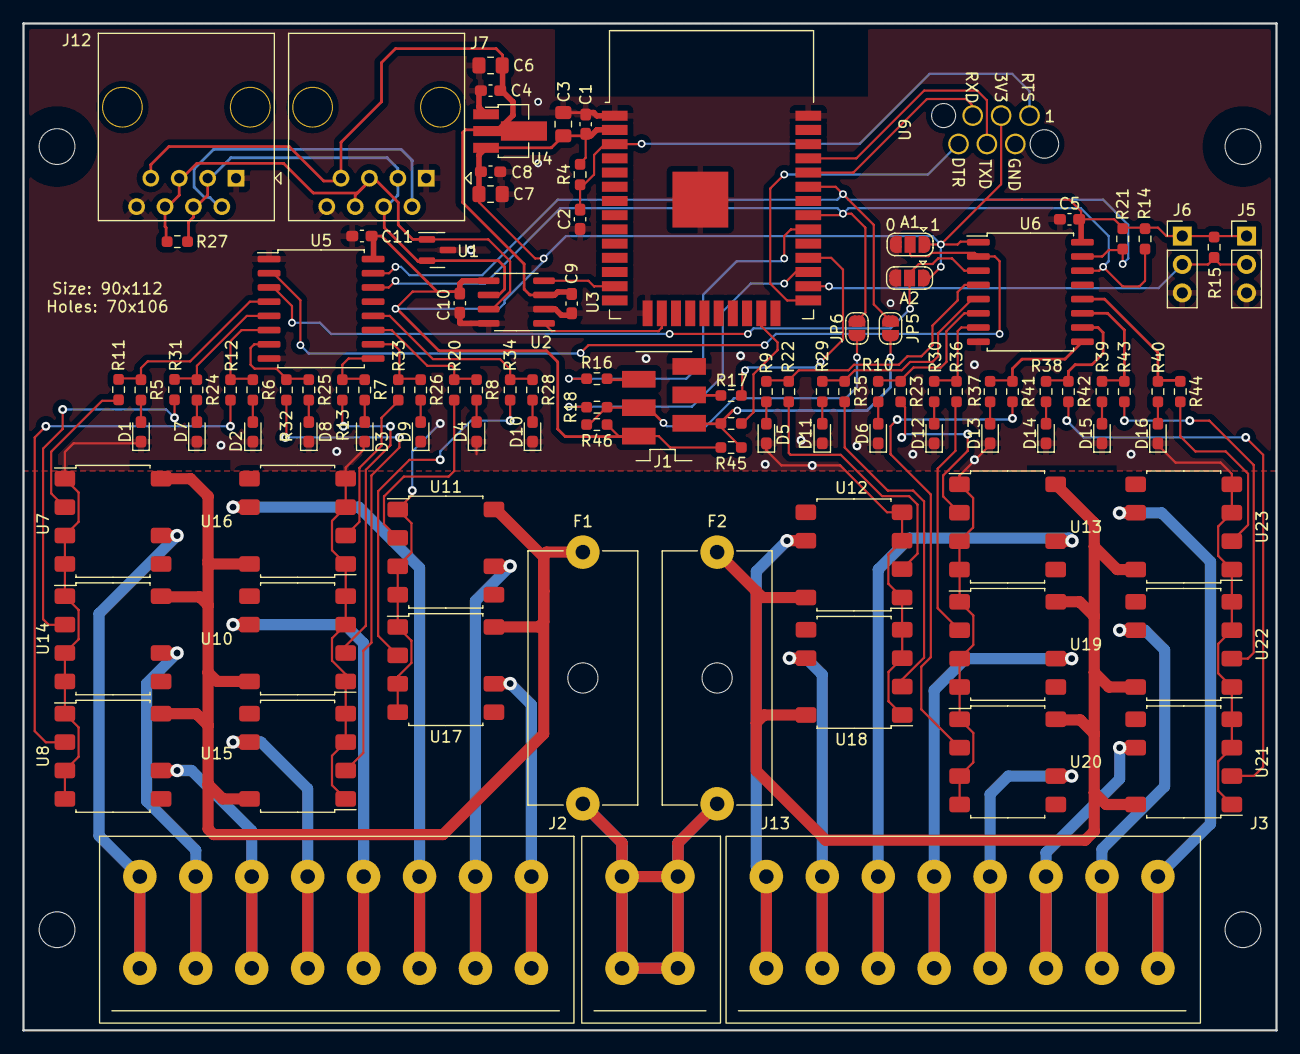
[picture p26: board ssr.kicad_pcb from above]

Board: 2 copper layers, 112.0 x 90.0 mm, 111 parts (0 on the bottom side), 92 nets.

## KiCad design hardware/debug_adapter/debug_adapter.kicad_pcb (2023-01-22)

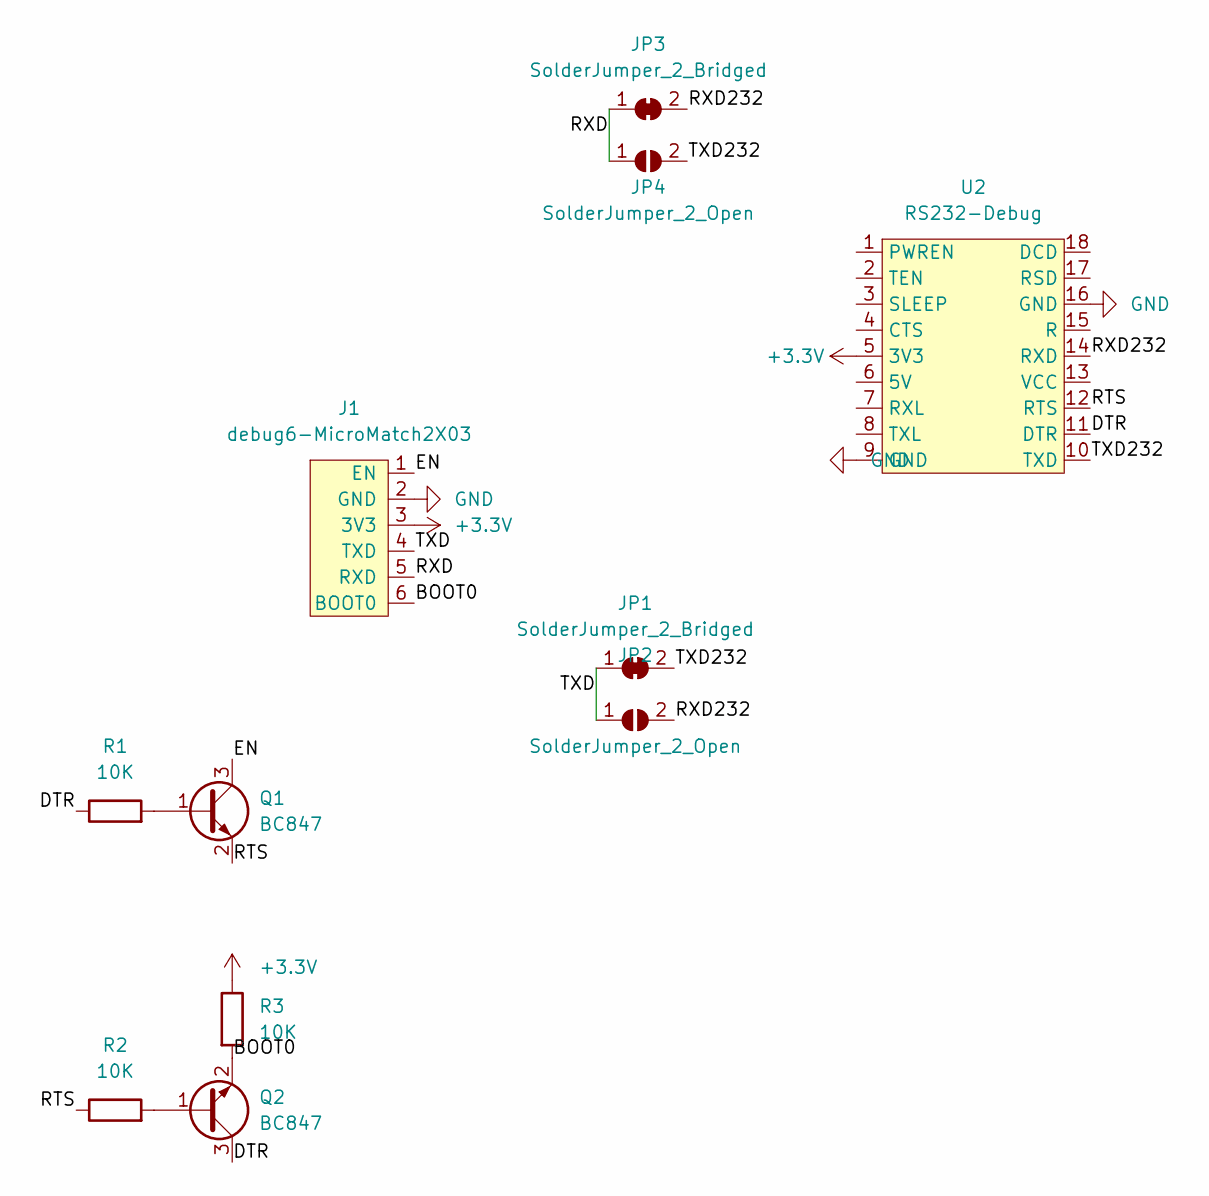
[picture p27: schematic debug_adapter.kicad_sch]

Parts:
J1: debug6-MicroMatch2X03; 02x03MicroMatch
JP1, JP3: SolderJumper_2_Bridged; SolderJumper-2_P1.3mm_Bridged_RoundedPad1.0x1.5mm
JP2, JP4: SolderJumper_2_Open; SolderJumper-2_P1.3mm_Open_RoundedPad1.0x1.5mm
Q1, Q2: BC847; SOT-23
R1, R2, R3: 10K; R_0603_1608Metric_Pad0.98x0.95mm_HandSolder
U2: RS232-Debug

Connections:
+3.3V: J1.3 (3V3), R3.1, U2.5 (3V3)
/BOOT0: J1.6 (BOOT0), Q2.2 (E), R3.2
/DTR: Q2.3 (C), R1.1, U2.11 (DTR)
/EN: J1.1 (EN), Q1.3 (C)
/RTS: Q1.2 (E), R2.1, U2.12 (RTS)
/RXD: J1.5 (RXD), JP3.1 (A), JP4.1 (A)
/RXD232: JP2.2 (B), JP3.2 (B), U2.14 (RXD)
/TXD: J1.4 (TXD), JP1.1 (A), JP2.1 (A)
/TXD232: JP1.2 (B), JP4.2 (B), U2.10 (TXD)
GND: J1.2 (GND), U2.9 (GND), U2.16 (GND)
unnamed: Q1.1 (B), R1.2
unnamed: Q2.1 (B), R2.2

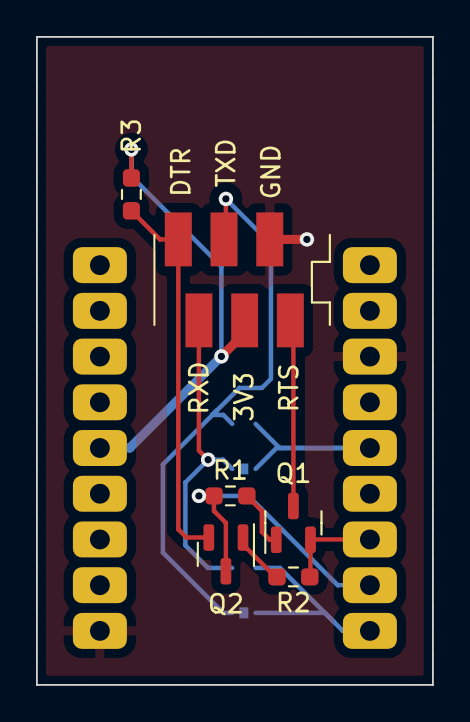
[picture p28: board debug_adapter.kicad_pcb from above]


Board: 2 copper layers, 22.0 x 36.0 mm, 11 parts (4 on the bottom side), 12 nets.

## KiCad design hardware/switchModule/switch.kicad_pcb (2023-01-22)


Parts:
C1, C4, C8, C9, C10, C11: 100n; C_0603_1608Metric_Pad1.08x0.95mm_HandSolder
C2: 1u; C_0603_1608Metric_Pad1.08x0.95mm_HandSolder
C3, C6, C7, C12: 10u; C_0603_1608Metric_Pad1.08x0.95mm_HandSolder
C13: C; C_0603_1608Metric_Pad1.08x0.95mm_HandSolder
CBST1: C; C_0603_1608Metric_Pad1.08x0.95mm_HandSolder
CFF1: C; C_0603_1608Metric_Pad1.08x0.95mm_HandSolder
D1, D4: D; D_SOD-123
J1, J3: Button-Sensors-MicroMatch2X03; 02x03MicroMatch
J2: Screw_Terminal_01x02; TerminalBlock_RND_205-00001_1x02_P5.00mm_Horizontal
J5, J6: IRDA; PinHeader_1x03_P2.54mm_Vertical
J7: RJ45-CAN; RJ45_OST_PJ012-8P8CX_Vertical
J8, J9, J10, J11: Conn_01x06_Female; 02x03MicroMatch
L1: L; L_1210_3225Metric_Pad1.42x2.65mm_HandSolder
R4, R7, R9, R11, R13: 10K; R_0603_1608Metric_Pad0.98x0.95mm_HandSolder
R5, R6: 2K2; R_0603_1608Metric_Pad0.98x0.95mm_HandSolder
R15: 4K7; R_0603_1608Metric_Pad0.98x0.95mm_HandSolder
R16, R17, R18, R19, R21, R22, R23, R24, R35, R36, R37, R38: 100R; R_0603_1608Metric_Pad0.98x0.95mm_HandSolder
R25: 100K; R_0603_1608Metric_Pad0.98x0.95mm_HandSolder
R27: R; R_0603_1608Metric_Pad0.98x0.95mm_HandSolder
RESR1: ?R; R_0603_1608Metric_Pad0.98x0.95mm_HandSolder
RFB1, RFB2: ?R; R_0603_1608Metric_Pad0.98x0.95mm_HandSolder
RRON1: ?R; R_0603_1608Metric_Pad0.98x0.95mm_HandSolder
SW1, SW2, SW3, SW4: SW_Push; SW_SPST_TL3305A
U1: PESD2CAN; SOT-23
U2: MCP2562-E-SN; SOIC-8_3.9x4.9mm_P1.27mm
U3: ESP32-WROOM-32
U4: MCP1703A-3302_SOT89; SOT-89-3_Handsoldering
U5: LM5163; Texas_R-PDSO-G8_EP2.95x4.9mm_Mask2.4x3.1mm_ThermalVias
U6: wuerthDebug6

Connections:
+3V3: C1.1, C3.1, C7.1, C8.1, C10.1, J1.1 (VCC), J3.1 (VCC), J5.1, J6.1, R4.2, R5.1, R6.1, R7.1, R9.1, R11.1, R13.1, R15.2, U2.5 (Vio), U3.2 (VDD), U4.3 (VO), U6.3 (3V3)
+5V: C4.1, C6.1, C9.1, D4.1 (K), J7.7 (+5V), U2.3 (VDD), U4.2 (VI)
+12V: J7.2 (+12V)
+48V: D1.2 (A), J2.1, J8.5, J8.6, J9.5, J9.6, J10.5, J10.6, J11.5, J11.6
/BOOT0: U3.25 (IO0), U6.6 (BOOT0)
/BST: CBST1.2, U5.7 (BST)
/CANH: J7.5 (CANH), J7.6 (CANH), R27.1, U1.1 (CANH), U2.7 (CANH)
/CANL: J7.3 (CANL), J7.4 (CANL), R27.2, U1.2 (CANL), U2.6 (CANL)
/CAN_RXD: U2.4 (RXD), U3.13 (IO14)
/CAN_TXD: U2.1 (TXD), U3.16 (IO13)
/DIM1: J11.2, R24.1
/DIM2: J10.2, R23.1
/DIM3: J9.2, R37.1
/DIM4: J8.2, R21.1
/DIM5: J11.1, R36.1
/DIM6: J10.1, R35.1
/DIM7: J9.1, R22.1
/DIM8: J8.1, R38.1
/EN: C2.1, R4.1, U3.3 (EN), U6.1 (EN)
/FB: CFF1.2, RFB1.1, RFB2.2, U5.5 (FB)
/ONEWIRE-IRDA: J5.2, J6.2, R15.1, U3.12 (IO27)
/RON: RRON1.2, U5.4 (RON)
/RXD: U3.34 (RXD0/IO3), U6.5 (RXD)
/SCL: J1.3 (B2/SCL), R6.2, R18.2
/SDA: J1.2 (B1/SDA), R5.2, R19.2
/SW: CBST1.1, L1.2, U5.8 (SW)
/SW1: J3.2 (B1/SDA), R7.2, SW1.2, U3.10 (IO25)
/SW2: J3.3 (B2/SCL), R9.2, SW2.2, U3.11 (IO26)
/SW3: J3.4 (B3), R11.2, SW3.2, U3.29 (IO5)
/SW4: J3.5 (B4), R13.2, SW4.2, U3.23 (IO15)
/TXD: U3.35 (TXD0/IO1), U6.4 (TXD)
/VIN: C11.1, C12.1, D1.1 (K), U5.2 (VIN), U5.3 (EN/UVLO)
GND: C1.2, C2.2, C3.2, C4.2, C6.2, C7.2, C8.2, C9.2, C10.2, C11.2, C12.2, C13.2, J1.6 (GND), J2.2, J3.6 (GND), J5.3, J6.3, J7.8 (GND), J8.3, J8.4, J9.3, J9.4, J10.3, J10.4, J11.3, J11.4, R25.1, RFB2.1, RRON1.1, SW1.1, SW2.1, SW3.1, SW4.1, U1.3 (GND), U2.2 (VSS), U2.8 (STBY), U3.1 (GND), U3.15 (GND), U3.38 (GND), U3.39 (GND), U4.1 (GND), U5.1 (GND), U6.2 (GND)
GND2: J7.1 (GND)
unnamed: C13.1, RESR1.1
unnamed: CFF1.1, D4.2 (A), L1.1, RESR1.2, RFB1.2
unnamed: J1.4 (B3), R17.2
unnamed: J1.5 (B4), R16.2
unnamed: R16.1, U3.30 (IO18)
unnamed: R17.1, U3.28 (IO17)
unnamed: R18.1, U3.27 (IO16)
unnamed: R19.1, U3.26 (IO4)
unnamed: R21.2, U3.9 (IO33)
unnamed: R22.2, U3.7 (IO35)
unnamed: R23.2, U3.31 (IO19)
unnamed: R24.2, U3.33 (IO21)
unnamed: R25.2, U3.14 (IO12)
unnamed: R35.2, U3.36 (IO22)
unnamed: R36.2, U3.37 (IO23)
unnamed: R37.2, U3.6 (IO34)
unnamed: R38.2, U3.8 (IO32)

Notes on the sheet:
DNP



Board: 2 copper layers, 48.0 x 49.0 mm, 63 parts (52 on the bottom side), 49 nets.

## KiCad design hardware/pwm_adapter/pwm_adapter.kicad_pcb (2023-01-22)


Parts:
A1, A2, A3: SolderJumper_3_Open; SolderJumper-3_P1.3mm_Open_RoundedPad1.0x1.5mm
C1, C3: 100n; C_0603_1608Metric_Pad1.08x0.95mm_HandSolder
C2, C4: 1u; C_0603_1608Metric_Pad1.08x0.95mm_HandSolder
D1, D2, D3, D4, D5, D6, D7, D8, D9, D10, D11, D12, D13, D14, D15, D16: PESD5V2S2UT; SOT-23
H1, H2, H3, H4: MountingHole; MountingHole_4.3mm_M4_DIN965
J1: WAGO250-204
J2, J3, J4, J5, J6, J7, J8, J9: WAGO250-208
J10, J11, J12, J13, J15, J16, J17, J18, J20, J21, J22, J23, J24, J25, J26, J27: Conn_01x06_Female; 02x03MicroMatch
J14: Conn_01x03; PinHeader_1x03_P2.54mm_Vertical
J19: Button-Sensors-MicroMatch2X03; 02x03MicroMatch
JP4: SolderJumper_2_Open; SolderJumper-2_P1.3mm_Open_RoundedPad1.0x1.5mm
R1: 4K7; R_0603_1608Metric_Pad0.98x0.95mm_HandSolder
R2: 1M; R_0603_1608Metric_Pad0.98x0.95mm_HandSolder
U1: DHT11; Aosong_DHT11_5.5x12.0_P2.54mm
U2, U3: PCA9685PW; TSSOP-28_4.4x9.7mm_P0.65mm

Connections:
+3.3V: A1.1 (A), A2.1 (A), A3.1 (A), C1.1, C2.1, C3.1, C4.1, J14.1, J19.1 (VCC), R1.1, U1.1 (VCC), U2.28 (VDD), U3.1 (A0), U3.28 (VDD)
+48V: J1.1, J1.2, J2.4, J2.8, J3.4, J3.8, J4.4, J4.8, J5.4, J5.8, J6.4, J6.8, J7.4, J7.8, J8.4, J8.8, J9.4, J9.8, J10.5, J10.6, J11.5, J11.6, J12.5, J12.6, J13.5, J13.6, J15.5, J15.6, J16.5, J16.6, J17.5, J17.6, J18.5, J18.6, J20.5, J20.6, J21.5, J21.6, J22.5, J22.6, J23.5, J23.6, J24.5, J24.6, J25.5, J25.6, J26.5, J26.6, J27.5, J27.6
/A1: A1.2 (C), U2.2 (A1), U3.2 (A1)
/A2: A2.2 (C), U2.3 (A2), U3.3 (A2)
/A3: A3.2 (C), U2.4 (A3), U3.4 (A3)
/DIM0: D1.2 (K), J2.1, J10.1, U2.22 (LED15)
/DIM1: D1.1 (K), J2.2, J10.2, U2.21 (LED14)
/DIM2: D2.2 (K), J2.5, J11.1, U2.20 (LED13)
/DIM3: D2.1 (K), J2.6, J11.2, U2.19 (LED12)
/DIM4: D3.2 (K), J3.1, J12.1, U2.18 (LED11)
/DIM5: D3.1 (K), J3.2, J12.2, U2.17 (LED10)
/DIM6: D4.2 (K), J3.5, J13.1, U2.16 (LED9)
/DIM7: D4.1 (K), J3.6, J13.2, U2.15 (LED8)
/DIM8: D5.2 (K), J4.1, J15.1, U2.13 (LED7)
/DIM9: D5.1 (K), J4.2, J15.2, U2.12 (LED6)
/DIM10: D6.2 (K), J4.5, J16.1, U2.11 (LED5)
/DIM11: D6.1 (K), J4.6, J16.2, U2.10 (LED4)
/DIM12: D7.2 (K), J5.1, J17.1, U2.9 (LED3)
/DIM13: D7.1 (K), J5.2, J17.2, U2.8 (LED2)
/DIM14: D8.2 (K), J5.5, J18.1, U2.7 (LED1)
/DIM15: D8.1 (K), J5.6, J18.2, U2.6 (LED0)
/DIM16: D9.2 (K), J6.1, J20.1, U3.22 (LED15)
/DIM17: D9.1 (K), J6.2, J20.2, U3.21 (LED14)
/DIM18: D10.2 (K), J6.5, J21.1, U3.20 (LED13)
/DIM19: D10.1 (K), J6.6, J21.2, U3.19 (LED12)
/DIM20: D11.2 (K), J7.1, J22.1, U3.18 (LED11)
/DIM21: D11.1 (K), J7.2, J22.2, U3.17 (LED10)
/DIM22: D12.2 (K), J7.5, J23.1, U3.16 (LED9)
/DIM23: D12.1 (K), J7.6, J23.2, U3.15 (LED8)
/DIM24: D13.2 (K), J8.1, J24.1, U3.13 (LED7)
/DIM25: D13.1 (K), J8.2, J24.2, U3.12 (LED6)
/DIM26: D14.2 (K), J8.5, J25.1, U3.11 (LED5)
/DIM27: D14.1 (K), J8.6, J25.2, U3.10 (LED4)
/DIM28: D15.2 (K), J9.1, J26.1, U3.9 (LED3)
/DIM29: D15.1 (K), J9.2, J26.2, U3.8 (LED2)
/DIM30: D16.2 (K), J9.5, J27.1, U3.7 (LED1)
/DIM31: D16.1 (K), J9.6, J27.2, U3.6 (LED0)
/OE: JP4.2 (B), R2.1, U2.23 (~OE), U3.23 (~OE)
/ONEWIRE: J14.2, J19.4 (B3), R1.2, U1.2 (IO)
/SCL: J19.3 (B2/SCL), U2.26 (SCL), U3.26 (SCL)
/SDA: J19.2 (B1/SDA), U2.27 (SDA), U3.27 (SDA)
GND: A1.3 (B), A2.3 (B), A3.3 (B), C1.2, C2.2, C3.2, C4.2, D1.3 (A), D2.3 (A), D3.3 (A), D4.3 (A), D5.3 (A), D6.3 (A), D7.3 (A), D8.3 (A), D9.3 (A), D10.3 (A), D11.3 (A), D12.3 (A), D13.3 (A), D14.3 (A), D15.3 (A), D16.3 (A), J1.3, J1.4, J2.3, J2.7, J3.3, J3.7, J4.3, J4.7, J5.3, J5.7, J6.3, J6.7, J7.3, J7.7, J8.3, J8.7, J9.3, J9.7, J10.3, J10.4, J11.3, J11.4, J12.3, J12.4, J13.3, J13.4, J14.3, J15.3, J15.4, J16.3, J16.4, J17.3, J17.4, J18.3, J18.4, J19.6 (GND), J20.3, J20.4, J21.3, J21.4, J22.3, J22.4, J23.3, J23.4, J24.3, J24.4, J25.3, J25.4, J26.3, J26.4, J27.3, J27.4, R2.2, U1.4 (GND), U2.1 (A0), U2.5 (A4), U2.14 (VSS), U2.24 (A5), U3.5 (A4), U3.14 (VSS), U3.24 (A5)
unnamed: J19.5 (B4), JP4.1 (A)

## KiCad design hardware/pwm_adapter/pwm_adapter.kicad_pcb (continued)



Board: 2 copper layers, 80.0 x 86.0 mm, 60 parts (38 on the bottom side), 43 nets.

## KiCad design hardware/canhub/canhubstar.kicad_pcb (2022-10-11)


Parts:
H1, H2, H3, H4: MountingHole; MountingHole_3.2mm_M3
J1: WAGO250-205
J2UPLINK1, J3, J4, J5, J6, J7, J8, J9, J10, J11, J12, J13: RJ45-CAN; RJ45_OST_PJ012-8P8CX_Vertical

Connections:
+5V: J1.2, J2UPLINK1.7 (+5V), J3.7 (+5V), J4.7 (+5V), J5.7 (+5V), J6.7 (+5V), J7.7 (+5V), J8.7 (+5V), J9.7 (+5V), J10.7 (+5V), J11.7 (+5V), J12.7 (+5V), J13.7 (+5V)
+12V: J1.3, J2UPLINK1.2 (+12V), J3.2 (+12V), J4.2 (+12V), J5.2 (+12V), J6.2 (+12V), J7.2 (+12V), J8.2 (+12V), J9.2 (+12V), J10.2 (+12V), J11.2 (+12V), J12.2 (+12V), J13.2 (+12V)
/CANH: J2UPLINK1.5 (CANH), J2UPLINK1.6 (CANH), J3.5 (CANH), J3.6 (CANH), J4.5 (CANH), J4.6 (CANH), J5.5 (CANH), J5.6 (CANH), J6.5 (CANH), J6.6 (CANH), J7.5 (CANH), J7.6 (CANH), J8.5 (CANH), J8.6 (CANH), J9.5 (CANH), J9.6 (CANH), J10.5 (CANH), J10.6 (CANH), J11.5 (CANH), J11.6 (CANH), J12.5 (CANH), J12.6 (CANH), J13.5 (CANH), J13.6 (CANH)
/CANL: J2UPLINK1.3 (CANL), J2UPLINK1.4 (CANL), J3.3 (CANL), J3.4 (CANL), J4.3 (CANL), J4.4 (CANL), J5.3 (CANL), J5.4 (CANL), J6.3 (CANL), J6.4 (CANL), J7.3 (CANL), J7.4 (CANL), J8.3 (CANL), J8.4 (CANL), J9.3 (CANL), J9.4 (CANL), J10.3 (CANL), J10.4 (CANL), J11.3 (CANL), J11.4 (CANL), J12.3 (CANL), J12.4 (CANL), J13.3 (CANL), J13.4 (CANL)
GND: J1.1, J1.4, J2UPLINK1.1 (GND), J2UPLINK1.8 (GND), J3.1 (GND), J3.8 (GND), J4.1 (GND), J4.8 (GND), J5.1 (GND), J5.8 (GND), J6.1 (GND), J6.8 (GND), J7.1 (GND), J7.8 (GND), J8.1 (GND), J8.8 (GND), J9.1 (GND), J9.8 (GND), J10.1 (GND), J10.8 (GND), J11.1 (GND), J11.8 (GND), J12.1 (GND), J12.8 (GND), J13.1 (GND), J13.8 (GND)


Board: 2 copper layers, 126.5 x 42.0 mm, 17 parts (0 on the bottom side), 5 nets.

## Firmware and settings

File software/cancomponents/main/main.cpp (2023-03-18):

/*
 * CAN Lightswitch module
*/

#include <cstdio>
#include <cstring>
#include <cstdlib>

#include <freertos/FreeRTOS.h>
#include <freertos/task.h>
#include <freertos/semphr.h>
#include <esp_err.h>
#include <esp_log.h>

#include "esp32-ha-lib/Button.hpp"
#include "esp32-ha-lib/CAN.hpp"
#include "esp32-ha-lib/Device.hpp"
#include "esp32-ha-lib/Update.hpp"
#include "esp32-ha-lib/THSensor.hpp"
#include "esp32-ha-lib/EEPROM.hpp"
#include "esp32-ha-lib/PresenceSensor.hpp"
#include "esp32-ha-lib/I2C.hpp"
#include "esp32-ha-lib/AmbientLightSensor.hpp"
#include "esp32-ha-lib/Nightlight.hpp"
#include "esp32-ha-lib/PinConfig.hpp"
#include "ExtensionBoard.hpp"
#include "Light.hpp"
#include "Relais.hpp"
#include "Console.hpp"
#include "ConsoleCommandDevice.hpp"
#include "Selftest.hpp"
/* --------------------- Definitions and static variables ------------------ */

#define TAG                     "CANLIGHTSWITCH"

static SemaphoreHandle_t shutdown_sem;


/* --------------------------- Tasks and Functions -------------------------- */

static PinConfig pin_config;
static CAN can;
static Update update(can);
static Device device(can);
static I2C i2c;
static Light light(can);
static THSensor ext_thsensor(can);
static THSensor thsensor(can);
static AmbientLightSensor ambient_light_sensor(can);
static Nightlight nightlight(can);
static PresenceSensor presence_sensor(can);
static ExtensionBoard extension_board;
static Relais relais(can);
static Selftest selftest(relais, light);
static Console console;
static ConsoleCommandDevice console_command_device(console, relais, light, selftest);
static PinConfig::switch_config_t onboard_switch = pin_config.get_onboard_switch_config();
static PinConfig::switch_config_t ext_board_switch = pin_config.get_ext_board_switch_config();
static Button sw1(can);
static Button sw2(can);
static Button sw3(can);
static Button sw4(can);
static Button ext_sw1(can);
static Button ext_sw2(can);
static Button ext_sw3(can);
static Button ext_sw4(can);

extern "C"
void app_main()
{
    //Create semaphores and tasks
    shutdown_sem  = xSemaphoreCreateBinary();
    
    pin_config.init();
    
    can.init(pin_config.get_can_config(), true);
    device.init();
    
    extension_board.sensor_board_setup(pin_config.get_ext_board_power());
    
    i2c.init();
    light.init(pin_config.get_onboard_pwm_config(), pin_config.get_ext_board_config());
    relais.init(pin_config.get_onboard_relais_config(), pin_config.get_ext_board_config());
    ext_thsensor.init(pin_config.get_ext_board_onewire(), pin_config.get_ext_board_config());
    thsensor.init(pin_config.get_onboard_onewire());
    
    nightlight.init(pin_config.get_ext_board_config());

    ambient_light_sensor.init(pin_config.get_ext_board_config());
    
    sw1.init(onboard_switch.sw1, Button::button_id_t::SW1);
    sw2.init(onboard_switch.sw2, Button::button_id_t::SW2);
    sw3.init(onboard_switch.sw3, Button::button_id_t::SW3);
    sw4.init(onboard_switch.sw4, Button::button_id_t::SW4);
    
    if (ext_thsensor.active || ambient_light_sensor.active() || light.ext_active() || relais.ext_active())
    {
        presence_sensor.init(pin_config.get_ext_board_pir());
    }
    else
    {
        extension_board.button_board_setup(pin_config.get_ext_board_power());
        ext_sw1.init(ext_board_switch.sw1, Button::button_id_t::EXT_SW1);
        ext_sw2.init(ext_board_switch.sw2, Button::button_id_t::EXT_SW2);
        ext_sw3.init(ext_board_switch.sw3, Button::button_id_t::EXT_SW3);
        ext_sw4.init(ext_board_switch.sw4, Button::button_id_t::EXT_SW4);
    }
    
    // init update at last; rollback will be disabled on init
    update.init(static_cast<uint8_t>(ICAN::DEVICE_t::Button));
    
    selftest.init();
    console.init();
    
    xSemaphoreTake(shutdown_sem, portMAX_DELAY);    //Wait for tasks to complete

    can.deinit();

    //Cleanup
    vSemaphoreDelete(shutdown_sem);
}

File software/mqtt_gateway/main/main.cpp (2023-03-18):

#include <stdio.h>
#include <string.h>
#include <stdlib.h>
#include "freertos/FreeRTOS.h"
#include "freertos/task.h"
#include "freertos/semphr.h"
#include "esp_err.h"
#include "esp_log.h"
#include <driver/gpio.h>
#include <driver/twai.h>

#include "nvs_flash.h"
#include "Update.hpp"
#include "CANUpdate.hpp"
#include "Logging.hpp"
#include "MQTT.hpp"
#include "WiFi.hpp"
#include "LAN.hpp"
#include "DeviceList.hpp"
#include "Web.hpp"
#include "esp32-ha-lib/CAN.hpp"
#include "esp32-ha-lib/PinConfig.hpp"
#include "BridgeDevice.hpp"
#include "BridgeLamps.hpp"
#include "BridgeRelais.hpp"
#include "BridgeButton.hpp"
#include "BridgeDebug.hpp"

/* --------------------- Definitions and static variables ------------------ */
//Example Configuration
#define DATA_PERIOD_MS                  50
#define NO_OF_ITERS                     3
#define ITER_DELAY_MS                   1000
#define RX_TASK_PRIO                    8       //Receiving task priority

static const char *TAG = "main";

static SemaphoreHandle_t shutdown_sem;

static PinConfig pin_config;
static MQTT mqtt;
static Logging can_logging(mqtt);
static Update update;
static CANUpdate can_update(can_logging);
static DeviceList device_list(can_logging);
static WiFi wifi;
static LAN lan;
static Web web(update, can_update, mqtt, can_logging, wifi, can_logging, device_list);
static BridgeDevice bridge_device(can_logging, mqtt, device_list);
static BridgeRelais bridge_relais(can_logging, mqtt, device_list);
static BridgeButton bridge_button(can_logging, mqtt, device_list);
static BridgeLamps bridge_lamps(can_logging, mqtt, device_list);
static BridgeDebug bridge_debug(can_logging, mqtt, device_list);

extern "C"
void app_main()
{
    //Initialize NVS
    esp_err_t ret = nvs_flash_init();
    if (ret == ESP_ERR_NVS_NO_FREE_PAGES || ret == ESP_ERR_NVS_NEW_VERSION_FOUND) {
      ESP_ERROR_CHECK(nvs_flash_erase());
      ret = nvs_flash_init();
    }
    ESP_ERROR_CHECK(ret);
    
    //lan.init();
    wifi.init();
    web.init();
    
    can_logging.init(pin_config.get_can_config(), false);
    device_list.init();
    //Create semaphores and tasks
    shutdown_sem  = xSemaphoreCreateBinary();

    if (wifi.mode() == WiFi::Mode::Client)
    {
        mqtt.init();
        bridge_device.init();
        bridge_relais.init();
        bridge_button.init();
        bridge_lamps.init();
        bridge_debug.init();
    }
    
    update.verified();
    
    xSemaphoreTake(shutdown_sem, portMAX_DELAY);    //Wait for tasks to complete

    twai_stop();
    //Uninstall CAN driver
    ESP_ERROR_CHECK(twai_driver_uninstall());
    ESP_LOGI(TAG, "Driver uninstalled");

    //Cleanup
    vSemaphoreDelete(shutdown_sem);
}

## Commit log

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2022-10-10 fix: Change include paths
    [main.cpp]
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2022-10-30 fix: Make version work and fix CAN filters
    [main.cpp]
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2022-11-15 Fix: rollershutter mode in gateway and relais
    [Relais.cpp]
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2023-01-22 fix: Stabilize relaise message queue and initialize off
    [Relais.cpp]
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2023-03-18 fix: Relais and BME680 initialization
    [Relais.cpp]
2023-03-23 fix: Fix a lot of minor bugs
    [pwm_adapter.scad, pwm_adapter_lid.stl, relais.scad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]
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2023-06-23 fix: Fix rollershuttermode
    [sensor_berker_v2.scad]
2023-07-11 fix: Change Relais and Update
    [LAN.cpp, Relais.cpp]
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2024-01-18 fix: Repair can baudrate and mqtt settings
    [LAN.cpp]
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2024-07-11 fix: Add GND to ext_clk_in
    [pwm_adapter.kicad_pcb, pwm_adapter.kicad_sch]
2024-07-11 fix: Correct pinning for switch v1
    [PinConfig.cpp]
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2024-07-11 fix: Fix device_pwm command
    [ConsoleCommandDevice.cpp]
2024-07-28 fix: Workging on update tweaking
    [main.cpp]
2024-07-29 feat: Adding error propagation for comp
    [Relais.cpp]
2024-07-29 fix: Fix hostname for LAN
    [LAN.cpp]
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2025-08-30 feat: Fix Echo and device Commands
    [ConsoleCommandDevice.cpp, main.cpp]
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2026-10-02 fix: Scope audit/license/SBOM CI to the single workspace Cargo.lock
    The per-crate CI matrices for audit.yml's advisories/licenses jobs and
    ci.yml's/release.yml's SBOM generation predate the one-Cargo.lock-per-
    workspace merge and were broken by it:
    - rustsec/audit-check runs `cargo audit --file <working-directory>/
    Cargo.lock`, which no longer exists per crate. One shared lock means
    one audit covers the whole workspace anyway, so drop the matrix
    entirely instead of pointing it somewhere that doesn't exist.
    - cargo-deny-action's own `cargo metadata` call picks up whichever
    crate's rust-toolchain.toml sits under its working directory; the
    "esp" channel those pin isn't installed in i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
2026-10-04 fix: Use the original gateway's partition table
    The gateway had inherited cancomponents' table (factory + two 1 MiB OTA
    slots). Switch to the C++ gateway's layout: no factory app, two 1792 KiB
    OTA slots, and the original offsets, so an OTA update can take over a
    deployed C++ gateway in place.
    [partitions.csv]
2026-10-04 feat: Drop WiFi, wired Ethernet only (DHCPv4 + SLAAC)
    WiFi is never used in practice and cost a lot: on the release build,
    flash image 898 -> 490 KiB, static DRAM 151 -> 54 KiB, stack budget
    41 -> 138 KiB (the heap existed only for esp-radio, so the project now
    has no allocator at all).
    - Remove the wifi module, esp-radio/esp-alloc, the WiFi config fields
    and keys (1-3 stay reserved) and the wifi console commands.
    - Ethernet comes up unconditionally and the stack runs dual-stack:
    DHCPv4 (announcing the configured hostname) plus IPv6 SLAAC. No link
    timeout: the driver reports link state to embassy-net.
    - MQTT broker: bracketed IPv6 literals, and AAAA lookup after A.
    - CONFIG_PARTITION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
2026-10-24 feat: Support DS18B20 temperature sensors on the Relais 1-Wire header
    Relais devices now measure up to 32 DS18B20 sensors on IO4 every 10 s and
    send them as TemperatureSensor frames (default every 30 s, settable with
    the `sensor-interval` CLI command and persisted).
    - cancomponents-core::ds18b20: CRC, ROM search (tested against a simulated
    bus), scratchpad decoding, CAN payload, sensor bank, health tracking and
    publish timer.
    - cancomponents-hardware::temperature: bit-banged 1-Wire driver and the
    measurement task; latest readings are available to other tasks via
    snapshot()/reading()/subscribe(). The sensor list is kept in flash.
    - A sensor that fails three cycles in a row is reporte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
2026-10-24 fix: Tune the heating controller after review
    - Rod stages use a positive hysteresis: stage n starts at n x 3000 W +
    300 W and keeps running down to n x 3000 W.
    - The default tank target is 75 C; the reference sensor stays settable
    with `tank-ref`.
    - The mixer is parked all the way at return (cold end) in direct
    operation and while no HeatingTarget arrives, and its start-up
    reference run drives to that end too.
    - The mixer waits 60 s after each adjustment.
    - Relay 11 (hot-water circuit pump) is documented as never driven by the
    controller, only by CAN/MQTT relay commands.
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2026-10-24 feat: Keep sensors in RAM only, add sensor probation and echo-restart switch
    - The list of known DS18B20 sensors is no longer stored in flash (the
    tank/flow role assignments of the heating controller still are).
    - A sensor that was just found, or came back after being lost, answers
    with its power-on value of 85 C until its first real conversion. Such a
    sensor is now on probation: it is sampled every 3 s until three readings
    in a row agree within 0.5 K, and only then are its values stored, sent
    and reported as recovered. `sensors` shows it as "settling".
    - The echo watchdog's restart can be switched off with the console command
    `echo-restart off` (persisted, on by default); `show`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
2026-10-24 fix: Time the 1-Wire slots with the CPU cycle counter
    In a release build the DS18B20 bus found no sensor at all (every bit read
    as 1, "bus search failed: BusError"), while the debug build worked. The
    slot timing used esp_hal::time::Instant, whose ESP32 implementation has to
    latch a timer before reading it and can return a stale value when read too
    soon afterwards; in the faster release code that shifted the sample points
    far enough to miss the sensor's answer.
    The driver now measures every slot from the edge that opens it, using the
    CPU cycle counter (a single register read). Verified on hardware: both the
    release and the debug build read both sensors, and a three minute run of
    the release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
2026-10-24 fix: Get the gateway's network and MQTT working on real hardware
    First test of the Rust gateway firmware on a (rev1) board, against a local
    MQTT broker and a HeatingControl node on the CAN bus.
    - MQTT: the client tracks at most four unconfirmed SUBSCRIBEs and refuses
    more, but the gateway never waited for the SUBACKs, so every topic after
    the fourth was silently never subscribed to (`canbus/debug/#` and the new
    heating topics). Each subscription is now confirmed before the next.
    `canbus/gateway/restart` was documented but not subscribed at all; it is
    now, and a retained restart message is ignored so it cannot cause a
    restart loop.
    - Ethernet: the RMII clock pin is a console sett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
2026-10-24 feat: Serve two MQTT brokers at the same time
    The gateway can talk to two brokers (e.g. Home Assistant and a Cerbo):
    one session per broker slot, each with its own connection, credentials
    and publish queue.
    - Commands are accepted from either broker and handled identically;
    everything the gateway publishes goes to every connected broker, and
    its `available` announcement to the one that just connected. A broker
    that is down or disabled is skipped instead of queueing.
    - gateway-core: BrokerConfig / MQTT_BROKERS and the keys of the second
    slot (Mqtt2*), plus a TLS-insecure flag per broker; parse_broker_uri
    now also understands mqtts:// (port 8883) and returns a BrokerAddress.
    - Conso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
2026-10-24 feat: Connect to MQTT brokers over TLS (mqtts://)
    The gateway speaks TLS 1.3 (embedded-tls, AES-128-GCM) to brokers given as
    mqtts://host[:8883]. As it has no clock and LAN brokers are mostly
    self-signed, it pins the broker's public key instead of validating a chain:
    `mqtt-trust` captures the presented certificate once (its fingerprint is
    logged), from then on the key and the handshake signature (ECDSA P-256/P-384
    or RSA-PSS) must match. `mqtt-untrust` forgets it, `mqtt-insecure on`
    accepts any certificate. The same commands exist for the second broker as
    `mqtt2-...`.
    The ESP32's TRNG is switched on through the ADC source for the TLS
    randomness, and a small heap (32 KiB) backs the RSA verif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
2026-10-24 feat: Add config, MQTT, system restart and device-type routes to the API
    GET/PATCH /api/v1/config and /mqtt/{primary,secondary} (passwords are
    write-only, changing a broker reconnects it), the pinned certificate of
    a broker (fingerprint, trust, forget), POST /system/restart and the
    per-device-type commands.
    JSON responses are rendered into one shared buffer before they are sent:
    picoserve's own Json formats into the socket's transmit ring and loses
    bytes when it has to start over after the ring wrapped, which reset the
    connection after the headers.
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2026-10-24 feat: Add the browser UI and fix TCP checksums on the Ethernet driver
    The gateway serves a UI (software/gateway-web, preact + htm, built with
    esbuild into gzip'd files that are checked in and embedded in the
    firmware) at /, /mqtt, /gateway and /devices/:device, a client of the
    REST API, with pages for the devices (relays, lamps, heating, settings,
    firmware), the two MQTT brokers and the gateway.
    esp-hal's Ethernet driver leaves the TCP checksums to the MAC, which gets
    them wrong for much of the traffic: responses over a few hundred bytes
    never arrived. The network stack computes them itself now. Firmware
    uploads are four times faster for it and for larger chunks (80 KiB/s).
    Docs: the REST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
2026-10-24 feat: Web UI fixes, bus actions, sensor list and heating manual mode
    - The Ethernet clock pin is no longer part of the web configuration (it
    follows from the hardware revision).
    - Form rows line up: fields with and without a hint no longer shift each
    other, and buttons next to fields sit level with the inputs.
    - The device list shows the device id and the type, both in hex.
    - The device list has the old UI's bus actions again: refresh, broadcast
    ping, silence on/off, restart all, ping by name or key, and a scan (every
    device is asked to announce itself).
    - GET /api/v1/sensors and a sensor page: every temperature/humidity/...
    sensor seen on the bus with its latest reading; also per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
2026-10-25 feat: Fold the heating messages into two, add named and assignable sensors
    CAN: the five heating messages (160-164) are replaced by HeatingCommand
    (165), one frame type with an operation code (target, energy, emergency,
    manual mode) packed into at most 5 bytes, and HeatingState (166), which is
    read with an R frame and no longer pushed. 160-164 are retired for good, so
    a node that is not updated yet can't read a new frame as an old one; with new
    numbers a version mismatch only leaves the heating without inputs, which it
    treats as the safe state.
    Sensors: SensorConfig (167) lists a node's temperature sensors, names them
    (7 characters, kept by serial on the node) and assigns their roles in the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
2026-10-25 feat: Update nodes over CAN in acknowledged blocks
    The firmware update over CAN streamed 8-byte frames paced by fixed delays and
    lost frames whenever the node wrote flash while the sender kept going. It now
    goes in blocks (default 1 KiB, a constant) with a CRC-16 per block: the sender
    sends a block back to back without delays, the node checks length and CRC and
    answers ack or nak, and the sender repeats a block that was refused or not
    answered. The node writes flash only while the sender waits for an answer, in
    4 KiB sectors, and a repeated block whose ack got lost is acknowledged again
    and not taken twice. Two message types (OtaControl 168, OtaData 169); the
    image CRC-32 is verified over th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
2026-10-27 docs: Note missing secure boot and flash encryption as technical debt
    The HTTPS device key, the passwords and the pinned broker certificates lie
    in flash in the clear. Encrypting the private key, flash encryption and
    secure boot (signed OTA images) are follow-ups.
2026-10-27 feat: Serve the web UI over HTTPS with central certificate management
    The web server answers on port 443 over TLS (MbedTLS via mbedtls-rs, the
    first TLS server for the target); port 80 answers 308 to https://. The
    console's `web-https off` goes back to plain HTTP on port 80.
    One ECDSA P-256 device key, made on the gateway and never exported, and a
    configured FQDN; the certificate is self-signed, uploaded from the
    gateway's own CSR, or enrolled and renewed over EST (RFC 7030, server
    always verified against the installed trust anchor). A new certificate
    replaces the active one only after a complete check, with one flash write;
    without a usable certificate the gateway makes a self-signed one.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
2026-10-27 fix: Serve a browser's parallel HTTPS connections, add `network` to the console
    Only two sockets listened on port 443, so a browser's further parallel
    connections were refused. Five cheap listening sockets now wait for the
    one TLS session; the session's large future (handshake and picoserve)
    and its buffers exist once, on the heap, only while a session runs, and a
    connection takes the session slot only once the client has sent data.
    Responses are collected in a buffer and sent as a few TLS records instead
    of one per header line.
    The console's `network` shows link, MAC, IPv4 and IPv6 addresses,
    gateways, DNS servers and the time. SNTP retries every 10 s until the
    first answer (the first requ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
2026-10-27 fix: Stop the ESP32 MAC from corrupting IPv6 frames
    The MAC's TX checksum insertion takes some IPv6 frames for IPv4 and writes
    the IPv4 header and TCP checksums into their source and destination
    addresses (bytes 10-11 and 36-37 of the IP header). The peer never sees
    those segments, so IPv6 TCP connections stalled after the first response,
    and with one TLS session at a time every following HTTPS request waited.
    esp-hal 1.2.2 always switches the insertion on; esp-hal's main has an
    option for it (esp-rs/esp-hal@0eb3e53), unreleased. The workspace now
    builds a patched copy of 1.2.2 (software/patches) that leaves the
    checksums to the network stack on the ESP32.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
2026-10-27 fix(smoltcp): Configure an address for every prefix of a Router Advertisement
    NdiscRepr::RouterAdvert keeps only the last Prefix Information option, so
    SLAAC configured one prefix per router: a router announcing a global and
    a ULA prefix left the interface with whichever came last (issue
    smoltcp-rs/smoltcp#1165). SLAAC now walks all options of the message
    through a new option iterator (wire::NdiscOptionIter), up to
    IFACE_MAX_PREFIX_COUNT prefixes. NdiscRepr itself is unchanged.
    The tests' config allows two prefixes now, for the new interface test.
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2026-10-27 fix: Don't run out of heap on a certificate upload
    A certificate or trust-anchor upload of more than ~10 KB over HTTPS made
    the gateway panic ("memory allocation of 11149 bytes failed") and hang:
    the body sat on the heap, its PEM was decoded into a second buffer, and
    next to a TLS session only ~21 KB are free.
    - PEM is decoded in place (x509::pem::decode_in_place), into the upload
    buffer itself.
    - Uploads are limited to 10 KiB: a stored chain holds at most 6 KiB of
    DER anyway.
    - The upload path allocates without panicking; a short heap answers 503
    no_memory.
    - The EST identity is one PEM body with certificate and key, as the REST
    API already took it; the key is decoded before the ce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
2026-10-27 fix: Keep the gateway's main stack from overflowing into the statics
    The first authenticated HTTPS request crashed the gateway at random
    (InstrProhibited at PC 0, a task header zeroed): the request path needed
    more than 60 KB of the ~47 KB main stack and wrote below it, past esp-hal's
    one-word stack guard. Async poll functions keep room for every future they
    build by value, and `Box::pin(f())` builds `f`'s future on the stack first;
    the router kept room for its largest handler (GET /tls held the 5 KB
    certificate status), three times over in picoserve's layers.
    - heap::boxed builds a future in its own frame and returns it as
    `Pin<Box<dyn Future>>`, so neither building nor polling it is inl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
2026-10-27 feat: Restart after a panic instead of halting forever
    esp-backtrace printed the panic/backtrace and then halted, so an
    unattended gateway or CAN component stayed dead until power-cycled
    (seen with out-of-memory panics, stack-guard hits and InstrProhibited).
    Enable esp-backtrace's `custom-halt` feature in both firmwares and
    define `custom_halt` in each binary; it forwards to
    `common_hardware::reset::restart_after_panic`, which busy-waits 1 s with
    the ROM delay (works with interrupts off) so the UART output drains,
    then calls `esp_hal::system::software_reset()`.
    Both firmwares now log the reset reason at boot, so a panic loop shows
    up as repeated `CoreSw` resets on the console.
    Co-Authored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
2026-10-31 feat: Trust Let's Encrypt's roots, check MQTT brokers against CAs
    One set of trusted CAs for EST and MQTT: Let's Encrypt's roots (ISRG
    Root X1, X2, YE, YR; 3.7 KB) are built in and trusted unless switched
    off, besides the CA certificates the user installs.
    An mqtts:// broker without a pinned key is now checked against those
    CAs instead of not being connected to: MbedTLS verifies the chain, the
    host name, the dates (SNTP) and the key usage; the host is sent as SNI.
    A certificate renewed with a new key (cert-manager, certbot) keeps
    working. A pinned key still wins.
    ADR 0020; HTTPS page, PATCH /tls built_in_roots, GET /mqtt tls_check,
    console tls-built-in-roots.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
2026-10-31 feat: Brightness in the sensor list, PWM lamps on the light switch page
    The gateway keeps the light switches' ambient light as a sensor
    (brightness, lux) next to the BME680's readings, so both show in the
    sensor list and on the device page. Only DS18B20s are named by their
    node: the gateway no longer asks a node about its BME680 or light
    sensor, and the UI doesn't wait for their names (GET /sensors
    named_by_node). The BME680's sub_id lives in common-core, shared by
    node and gateway.
    A light switch in PWM extension mode gets the lamp controls on its
    device page, for banks 1-16.
2026-11-01 feat: Discovery: nodes announce themselves until the gateway acks
    A broadcast ping made every node answer at once, and the parameter
    request that followed made each send nine frames more: with ~60 nodes
    the transmit retries ran out and devices went missing.
    Now a node sends Discovery (43) with its name after start, after a
    rename and when the gateway asks (Discovery R frame, to everybody or
    one node), and repeats until the gateway's DiscoveryAck (44): first
    after a random 0-2 s, then a random 300 ms-2 s for five tries, then
    2-5 s. The gateway takes the name from the announcement, acks at once
    and asks only new nodes for their settings. It asks for discovery when
    it starts; the web UI's Scan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
2026-11-01 feat: Home Assistant MQTT discovery from the gateway
    With ha-discovery on (console, PATCH /mqtt home_assistant, the MQTT
    page; off by default), the gateway publishes retained Home Assistant
    discovery configurations on the primary broker: a device per CAN
    device, a sensor per reading seen (device class and unit), a motion
    binary_sensor per presence sensor, and device triggers for single,
    double, triple, hold and release per button. They point at the state
    topics it publishes anyway. They go out when something is new or
    renamed, after connecting, and when Home Assistant reports online;
    unchanged ones aren't sent again. Configurations travel through a
    retained channel of their own (up to 768 by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
2026-11-01 fix: MQTT: free the client's buffer after each received packet
    rust-mqtt keeps the topic and payload of every received PUBLISH in the
    2 KiB bump buffer and never gives the room back; that is up to the
    caller (BumpBuffer::reset). Nothing did, so after 2 KiB of received
    messages - some fifty commands - the next one didn't fit: the poll
    failed, the gateway dropped the connection and reconnected, and that
    message was lost.
    Reproduced on the test gateway with a local broker: 100 messages of
    ~42 bytes on canbus/debug/zz, and the broker logs "connection closed by
    client" in the middle of them.
2026-11-01 fix: Reconnect a broker when the console changes its settings
    The console's broker setters (mqtt[2]-uri, -user, -password, -enabled,
    -insecure, -trust, -untrust) only stored the setting, so the running
    connection kept going with the old one until it dropped by itself; e.g.
    `mqtt2-enabled off` left the broker connected. Reconnect the slot after a
    successful store, as the web API does.
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2026-11-01 fix: Console: 5.4 KB less RAM for its task's future
    The console task's future was 12 KB, static, and took that much from the
    main stack (the stack is what the statics leave of SRAM2). Two thirds of
    it held nothing useful:
    - `respond(writer, &reply()).await`: the reply's temporary lives across
    the `.await`, and rustc gives each such temporary a slot of its own in
    the future, never shared with the other match arms. 28 call sites of
    160-byte strings in `handle_command`, 4.6 KB. `respond` now takes the
    reply by value; it lives in `respond`'s future, which the arms share.
    - `show` kept the pinned MQTT certificate (2 KiB) across the line it
    writes; it is now dropped in a block before th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
2026-11-01 perf: MQTT buffers into the ROM's boot stacks in SRAM1: +31.7 KB stack
    The two broker slots' buffers (TCP windows and TLS records) took 33.8 KB
    of SRAM2, where every byte of statics is a byte less main stack. They
    now fill the ROM's boot stacks in SRAM1, which esp-hal leaves unused and
    ESP-IDF gives to its heap once it runs: 0x3FFE0440-0x3FFE3F20 and
    0x3FFE4350-0x3FFE7E30, 15,072 bytes each (the ROM's data around them
    stays reserved). rom-boot-stacks.x makes them sections of their own, so
    the linker checks the sizes; the heap stays as it was.
    To fit, the buffers got smaller where they were larger than needed:
    - The TLS write record 2.5 -> 1 KiB: embedded-tls splits longer writes
    into seve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
2026-11-01 docs: RAM: the MQTT buffers in SRAM1, and why they are that size
    The map, the statics and the stack after the console fix and the move
    of the MQTT buffers: stack 75,380 B, 40,072 B never touched after five
    minutes (was 2,720 B). A new section gives each MQTT buffer's reason,
    with the measured certificate chain record (4,119 B).
2026-11-01 fix: Console: the key pin's reply by value, like the others
    #31 came from before #27 and passed its tls-status line as a reference.
    That still compiles, but keeps the temporary across the .await, which
    #27 removed everywhere else.
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2026-11-01 feat: Measured CO2 and the raw gas resistance on the bus and the gateway
    Two new fixed-point sensor messages, to calibrate the BME680's CO2
    equivalent against a real CO2 sensor:
    - `Co2Sensor` (159): CO2 measured by an NDIR sensor (an SCD30 on the
    light switch's sensor board, sub_id 0x3000_0061), ppm.
    - `GasResistance` (170): the BME680's raw gas resistance, kOhm.
    The gateway publishes them as `canbus/co2_measured/...` and
    `canbus/gas_resistance/...`, lists them on the sensors page, and
    announces them to Home Assistant (CO2 as carbon_dioxide; the gas
    resistance as a diagnostic entity, off by default). The CO2 equivalent
    is now labelled "CO2 equivalent" there, to tell the two apart.
    Co-Au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

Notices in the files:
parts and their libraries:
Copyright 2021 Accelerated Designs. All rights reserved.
